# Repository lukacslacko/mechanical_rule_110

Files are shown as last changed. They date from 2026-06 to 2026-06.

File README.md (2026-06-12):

# MECH-110 — a 3D-printable mechanical Rule 110 machine

A hand-cranked, fully 3D-printable machine that computes the
[Rule 110](https://en.wikipedia.org/wiki/Rule_110) cellular automaton —
which is Turing complete — on punched paper tape. One crank revolution
reads three neighboring cells from the input tape, decides the next-generation
cell mechanically, and punches it (plus a fresh sprocket hole) into the
output tape. No springs, no electronics, no metal parts.

The entire mechanism was designed *and verified* in software before printing:
every part is generated parametrically, the full cycle is collision-swept in
all 8 input states, and the assembly order is checked step by step — so
nothing has to be assembled "through the fourth dimension".

## The trick: no 8-way decoder needed

Rule 110 factors into

```
new = (C OR R) AND NOT (L AND C AND R)
```

so instead of an 8-position code wheel, the logic train is just:

- three sensing **pins** that drop into tape holes,
- an **AND3 guillotine** plate resting on all three pin collars (descends
  fully only for 1-1-1) carrying a blocker finger,
- two **OR rockers** (one per pin C, R) whose tips drive
- a horizontal **swing-arm interposer** that slides a block between the
  cam-driven hammer and the data punch.

The 111-veto wins its race by construction: pins ride a cam-timed bail down,
so all drops are rate-synchronized; the blocker enters the swing path before
the arm can start moving.

## Highlights

- **Geneva drive**: 6-slot Geneva + locking ring indexes both tapes exactly
  one 8 mm pitch per revolution; the locking crescent is computed numerically
  from the swept wheel silhouette.
- **Rib cams + slide-in keys**: positive-return cams that still allow the
  one-piece camshaft to drop radially into open bearings — the window
  followers are closed by snap-in keys after the shaft is seated.
- **Single source of truth**: cam lift functions, the kinematic model and the
  cam solids all derive from the same code (`camprofiles.py`), so geometry
  and simulation cannot disagree.

## Verification pipeline

| stage | command | what it proves |
|---|---|---|
| logic & kinematics | `pytest tests/` | the mechanism model computes Rule 110 in all 8 cases; phase discipline; veto race; cycle closure |
| motion sweep | `python scripts/verify_motion.py` | 8 cases × 360° × 1°: no part-pair interference (FCL + exact mesh booleans) |
| assembly order | `python scripts/verify_assembly.py` | a 51-step insertion sequence with swept approach paths |
| viewer | `python scripts/export_viewer.py` | animated three.js model → `out/viewer.html` |

## Assembly

**[Step-by-step assembly guide with renders → ASSEMBLY.md](ASSEMBLY.md)** —
generated from the same collision-verified insertion sequence that
`scripts/verify_assembly.py` checks.

## Quick start

```sh
uv venv .venv && uv pip install --python .venv/bin/python \
    build123d trimesh python-fcl manifold3d shapely scipy rtree networkx pytest
.venv/bin/python -m pytest tests/ -q
.venv/bin/python scripts/build_stls.py        # writes out/parts/*.stl
.venv/bin/python scripts/verify_motion.py
.venv/bin/python scripts/export_viewer.py     # open out/viewer.html
```

Open `out/viewer.html` in a browser: drag the crank-angle slider, pick the
(L,C,R) input case, press play.

## Layout of the repo

- `DESIGN.md` — full mechanism architecture and the design decisions.
- `STATUS.md` — current verification status and open items.
- `src/mech110/` — parameters, cam profiles, kinematics, world layout, the
  parametric part builders (build123d), Geneva geometry, assembly registry.
- `scripts/` — STL export, motion sweep, assembly check, viewer export.
- `out/parts/` — generated STLs; `out/viewer.html` — the animated model.

## Status

Motion-certified (zero interference across all sampled states); assembly
sequence verified with a handful of residual snap-fit contacts still being
classified — see `STATUS.md`. Not yet printed: tolerance/printability review
is the next step. This is a "Turing complete in principle" demonstration
piece, not a practical computer — exactly as intended.

## License

MIT

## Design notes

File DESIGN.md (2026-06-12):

# MECH-110 — a 3D-printable Rule 110 machine on punched paper tape

One crank revolution = one machine cycle = one cell of the next generation
computed and punched. Hole = 1, no hole = 0.

## 0. The logic simplification (no 8-way code wheel needed)

Rule 110: new(i) = f(L, C, R) with table
111→0, 110→1, 101→1, 100→0, 011→1, 010→1, 001→1, 000→0.

f is 0 exactly for {111, 100, 000}. Since 100 and 000 are exactly the patterns
with C=0 and R=0:

    new = (C OR R) AND NOT (L AND C AND R)

Mechanically:
- **AND3** = a guided "guillotine" plate whose three feet rest on the collars
  of all three sensing pins. It descends fully only if *all three* pins drop
  into holes (min function), and carries a blocker finger.
- **OR** = two independent gravity-follower rockers (one for pin C, one for
  pin R), see-saws on a common axle: the ledge side rests on its pin's collar
  (one-way), so the tip side rises when *either* pin drops (max function at
  the contact). One-way resting contacts mean a stalled rocker can never
  prevent a pin from completing its drop — the logic is fully decoupled.
- The rocker tips ride in a 45° V-groove on the foot of a **swing-arm
  interposer** rotating about a *vertical* pivot: rising tips swing the
  interposer block horizontally (at constant height!) into the gap between
  the punch hammer and the data punch head; descending tips pull it back out
  (positive both ways, no springs, no gravity bias needed).
- The AND3 finger, when fully down, stands in the swing path and stops the
  arm after ~1 mm of block travel (= veto). Veto wins the race by
  construction: pins don't free-fall, they ride the cam-controlled bail down,
  so all drops are rate-synchronized; the finger enters the swing path at
  0.8 mm of descent while the V-groove lag delays arm motion until ~1.1 mm.

So: 3 pins + 1 plate + 2 rockers + 1 swing arm replace the 8-position wheel.

## 1. Tape format

- Paper strip, width 25 mm (cut from 57 mm adding-machine roll, or any paper).
- Row pitch P = 8 mm along the tape.
- Track 1 (guide/sprocket): ⌀3.2 mm holes, every row, near reference edge.
- Track 2 (data): ⌀4.0 mm holes, hole = 1.
- Two parallel tape paths through the machine, side by side:
  path A = input (reader), path B = output (punches).
  Loop mode: the tape leaving B U-turns outside the machine and re-enters A.

## 2. Coordinate system & layout

X = tape travel direction, Y = across tape (all shaft axes along Y), Z = up.

- Tape bed (with die holes, sprocket grooves, chad chute) at mid height.
- **Sprocket shaft** above the tape, teeth pointing down through the guide
  holes into bed grooves: two 6-tooth sprockets (pitch radius = 6P/2π ≈ 7.64 mm),
  one per tape path, on one shaft → both tapes advance in lockstep.
- **Main camshaft** higher up, parallel. Carries all cams + Geneva driver +
  crank. Vertical center distance to sprocket shaft = Geneva center distance d.
- **Geneva (6-slot)**: driver crank (radius 0.5·d) on the camshaft's left end,
  wheel (radius 0.866·d) keyed to the sprocket shaft's left end, both outside
  the left frame plate. 60° of wheel per rev = exactly one tooth = one pitch P.
  Locking ring on the driver keeps tapes registered during dwell.
- **Crank handle** on the camshaft's right end.

## 3. Stations

**Reader (over path A)**: three pins at X-spacing P over the data track,
rounded ⌀3.5 tips, sliding in a comb block. A lift bail under the pin collars
(one-way: lift only, lost motion downward) is driven by a groove cam — pins are
held 3 mm above the paper during tape advance, released to settle by gravity
during the read dwell. A pin over a hole drops ~2.5 mm into a bed groove;
a pin over paper rests on it (a few grams — cannot pierce).

**Logic (beside/above reader)**: AND3 bar, OR rocker, pendulum interposer,
as in §0. All gravity-returned; no metal springs anywhere in the machine.

**Punch station (over path B)**: punches guided in a block with integral
stripper; die holes in the bed; chads fall through to the base.
- Guide punch (⌀3.2-hole) — slider with integral punch tip, positively
  driven *both ways* by its cam (window follower). Punches every cycle.
- Data punch (⌀4-hole) — cam-driven hammer; the hammer's face pad presses
  the interposer block which presses the punch-head flange (drive), and a
  C-lip under the flange yanks the punch back out of the paper on retract
  (positive extraction — pierced paper grips the pin too hard for gravity).
  When the interposer is out, the face pad's edge passes clear of both the
  blocked block and the flange: the hammer strokes empty. A small
  counterweighted return rocker holds the idle punch at rest height.
Punch tips are pyramidal piercing points (printable); the design leaves a
drop-in option for steel pins (ground 4 mm nail) if PLA edges dull.

**Cam-follower construction**: every cam is an annular RIB (radial band of
varying center radius, walls = pitch curve ±1.5 mm) protruding axially from
its hub disc; each follower is a slider with a window straddling the rib —
lower boss outside the rib, upper boss inside the ring. The upper boss is a
separate slide-in KEY (inserted along Y after the camshaft is seated), which
is what makes radial drop-in assembly of the camshaft possible at all.
Punch station X is an exact integer multiple of P upstream of sprocket B's
top-dead-center, so machine-punched guide holes land on the teeth.
To start a raw tape, ~3 guide holes are hand-punched with a printed jig.

## 4. Cycle (one camshaft revolution, θ = 0…360°)

| θ | action |
|---|---|
| 0–120° | Geneva engaged → both tapes advance exactly P. Pins held up, punches up. |
| 130–170° | bail lowers; pins settle into holes / onto paper |
| 170–205° | logic settles: AND3 bar lands, OR rocker pushes, interposer swings in (or is vetoed / not pushed) |
| 210–280° | punch stroke down + return (guide always, data iff interposer in) |
| 290–355° | bail lifts pins; bars/rocker/interposer reset by gravity |

Tapes only move while pins and punches are clear; punching only happens during
Geneva dwell (locking ring engaged).

## 5. Frame & assembly strategy

Two side plates + bed + top bearing bridges, joined by printed tab-and-wedge
joints (no screws required; M3 holes provided as backup). All shaft bearings
are **split pillow blocks**: shafts (printed in one piece with their cams /
sprockets) drop in radially, then a printed cap closes the bearing — nothing
has to be threaded axially through closed holes. Geneva wheel and crank key
onto hex shaft ends after the shafts are seated.

## 6. Verification plan (all in software, before printing)

1. **Logic model** (`rule110.py`): discrete simulation of pins → bars →
   interposer → punch for all 8 neighborhoods, asserted equal to Rule 110;
   plus multi-generation tape simulation against a reference implementation.
2. **Single source of truth for motion** (`camprofiles.py`): each cam's lift
   function is defined once, analytically; the cam *solid* is lofted from it
   and the follower *pose* is computed from it ⇒ cam/follower agreement by
   construction. All intended contacts are modeled with explicit running
   clearance (≥0.15 mm), so the nominal mechanism has **zero** intersections.
3. **Motion collision sweep** (`verify/collide.py`): θ sampled at ≤1° over a
   full cycle × all 8 input cases (and tape-with-holes solids in the loop);
   pairwise mesh collision via FCL. *Any* intersection = design error.
   Near-miss report (<0.15 mm clearance) as warnings.
4. **Assembly check** (`verify/assemble.py`): every part has an ordered
   insertion path (sequence of linear moves); each step is sweep-checked
   against the union of already-placed parts. Catches "needs 4th dimension".
5. **Printability** (`verify/printability.py`): per part — bed fit
   (220×220×250 default), min wall ≥ 1.2 mm, chosen print orientation noted,
   overhang sanity.
6. **Animated viewer** (`export/viewer.py`): self-contained three.js HTML,
   θ slider + play, selectable input case, exploded-view assembly animation.

## 7. Print parameters (defaults, all in `params.py`)

PLA, 0.4 nozzle. Running fits 0.25 mm/side, locational 0.15, press 0.05.
Shafts ⌀8 printed. Bed 220×220×250.

## 8. Registration & bookkeeping

Output row is punched k·P offset from the input row being read (k = fixed
station offset). In two-tape mode this is just indexing; in loop mode it adds
a constant spatial shift per generation, which composes harmlessly with the CA.

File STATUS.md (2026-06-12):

# MECH-110 status (end of session 1)

## VERIFIED
- Logic+kinematics: 19 tests green (mechanism == Rule 110 for all 8 cases,
  phase discipline, 111-veto race, cycle closure).
- MOTION: full sweep CLEAN - 8 cases x 360deg x 1deg, all 44 parts, fcl +
  manifold-boolean second pass: zero real interference
  (scripts/verify_motion.py).
- ASSEMBLY (scripts/verify_assembly.py): 51-step sequence runs; structural
  blockers all resolved (axle threads along X after rockers; camshaft turned
  to theta=180 for sprocket-shaft drop; cap pins from outer faces before
  wheel/crank; swing-arm enters tilted -34deg, 8mm rise). 8 residual
  candidate contacts, believed noise/snap-fits but NOT yet boolean-classified:
  key_gp 0.57 (snap barb squeeze ~0.3 by design), key_ham 1.29 (recheck after
  the hub-boss removal!), sprocket_shaft 2.11 & geneva_wheel 1.74 vs camshaft
  (slide-on profile - diagnose with boolean bbox), spk_clip 1.51 (deep snap),
  cp_cl 0.2 (ok), crank 0.045 (ok).
- out/viewer.html: animated three.js model (crank slider, 8 input cases).
- out/parts/*.stl: all printable parts, single solids, watertight after
  vertex merge.

## Statics (added after session 1)
- Force-closure was NOT covered by the geometric sweeps: all three rockers
  were tip-heavy as built (pads would not follow the pins; punch not
  supported). Fixed with pad-side ballast blocks / a larger counterweight;
  locked in by tests/test_mass_balance.py (CenterOf.MASS moment margins).
- STL filenames now carry their assembly-step prefix (NN_name.stl);
  loaders strip it via assembly.strip_step_prefix().

## NEXT
1. Boolean-classify the 8 assembly residuals (reuse verify_motion's bvol).
2. Re-run verify_assembly after the spoked-hub boss removal.
3. Printability pass (bed fit OK by construction; check min walls: gp key
   hole web 0.4, pillar x21..21.5 in and3, rocker foot ribs).
4. Tolerance review for FDM (0.25 running fits assumed).
5. Hand-punch jig for tape leaders (not yet modeled).
6. DESIGN.md final sync (tower guides, east-tip rockers, shelf rail,
   3-spoke hubs, T-cap reversion to pinned plug caps).

Run: .venv/bin/python scripts/{build_stls,verify_motion,verify_assembly,
export_viewer}.py ; tests: -m pytest tests/ -q

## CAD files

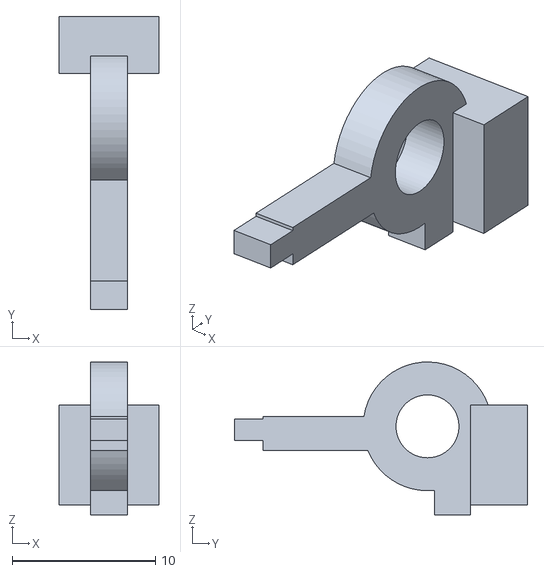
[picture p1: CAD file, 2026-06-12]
out/parts/19_return_rocker.stl
7.00 x 20.5 x 10.7

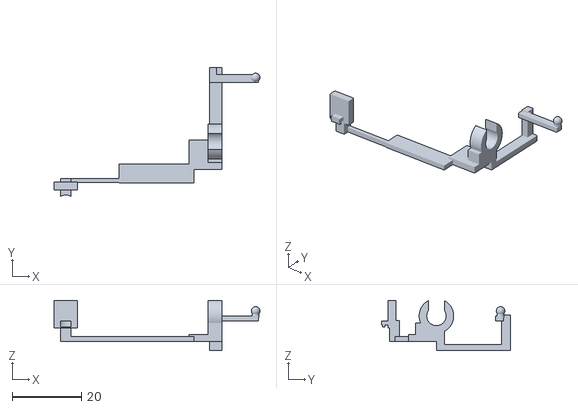
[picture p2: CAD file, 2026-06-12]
out/parts/12_rocker_r.stl
59.4 x 37.3 x 14.5

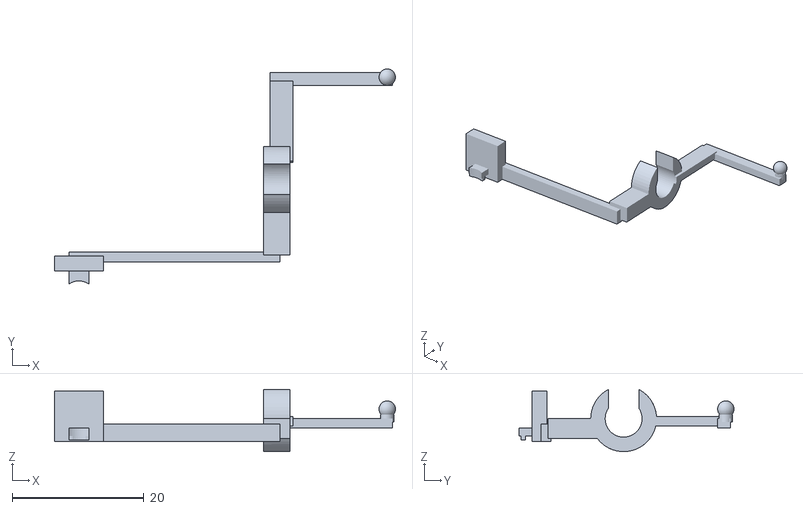
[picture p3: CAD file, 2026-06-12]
out/parts/12_rocker_c.stl
51.7 x 32.6 x 9.44

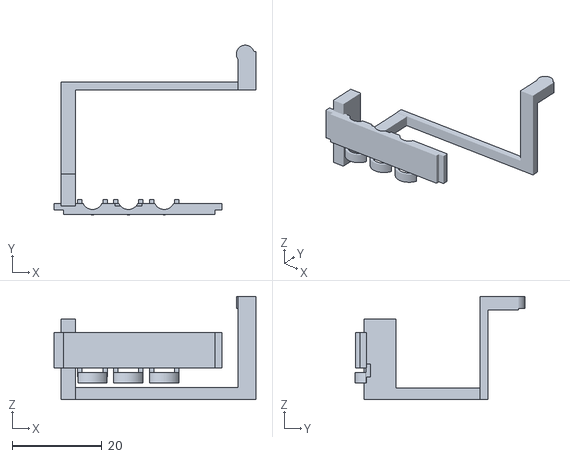
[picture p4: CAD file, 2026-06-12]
out/parts/14_and3.stl
45.1 x 37.9 x 23.0

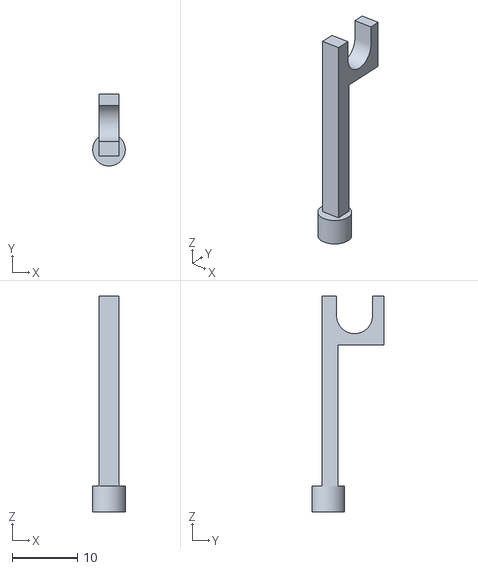
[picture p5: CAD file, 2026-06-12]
out/parts/11_lcol_right.stl
5.00 x 11.0 x 33.0

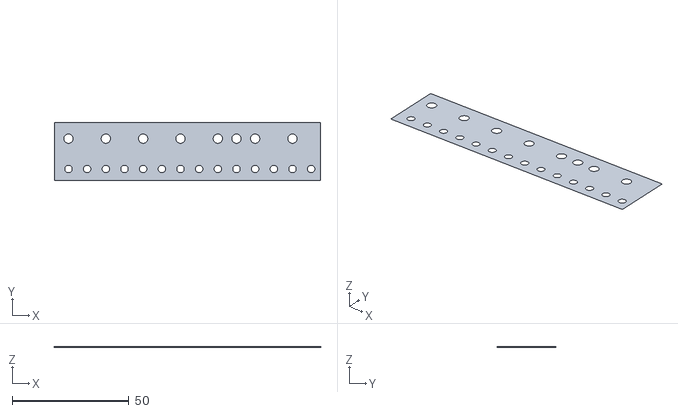
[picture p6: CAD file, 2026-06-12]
out/parts/04_tape_a_110.stl
114.0 x 25.0 x 0.1

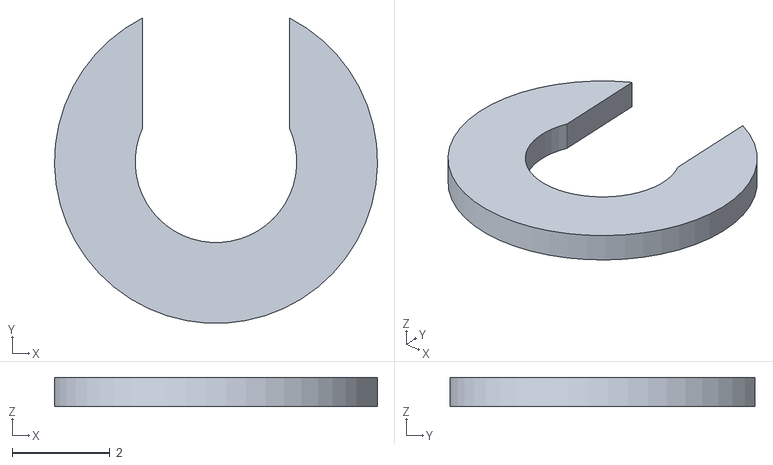
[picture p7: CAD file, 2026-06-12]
out/parts/18_pivot_clip.stl
6.60 x 6.23 x 0.6

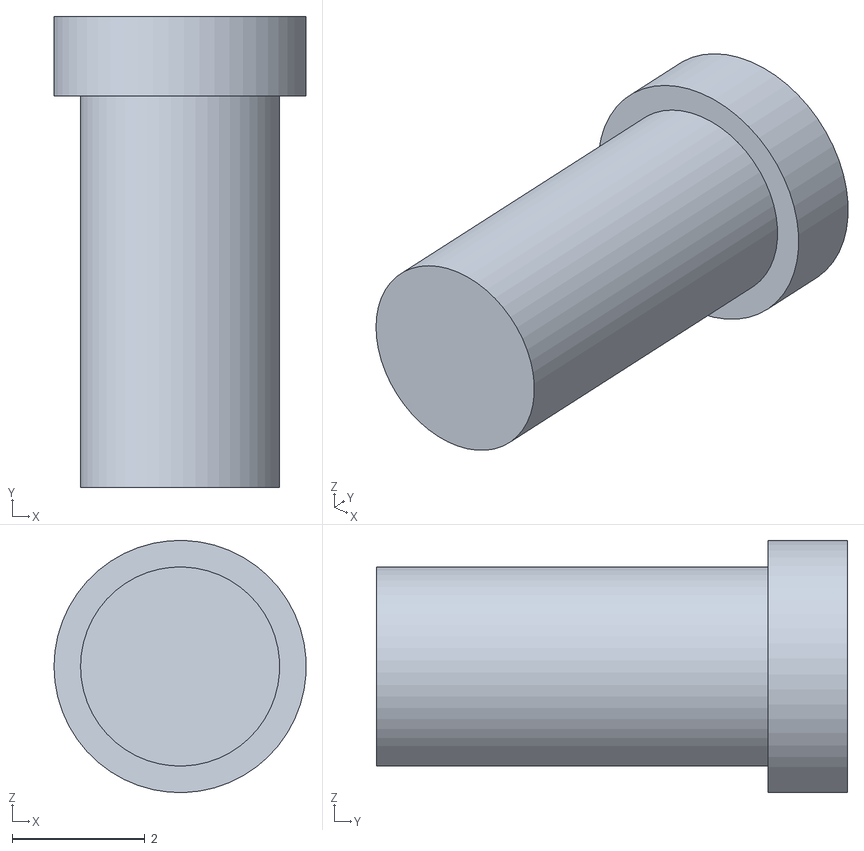
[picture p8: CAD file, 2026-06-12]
out/parts/29_cp_cr2.stl
3.80 x 7.10 x 3.80

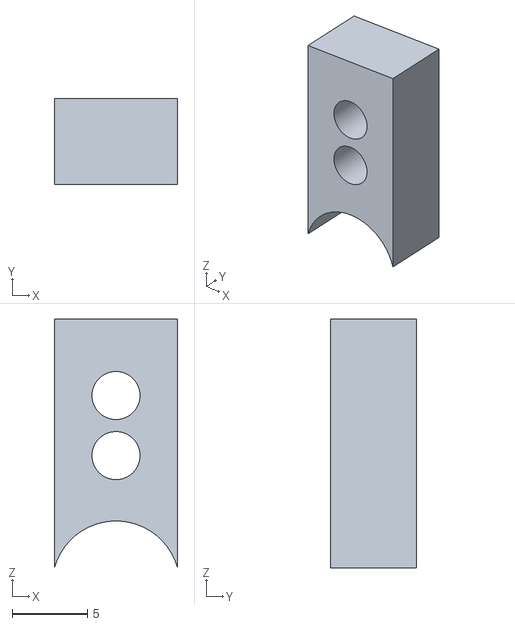
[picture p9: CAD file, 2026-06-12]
out/parts/29_cap_cam_left.stl
8.20 x 5.70 x 16.6

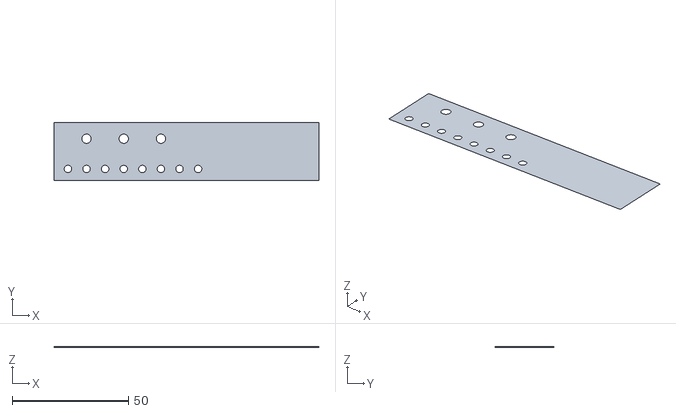
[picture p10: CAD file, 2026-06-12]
out/parts/04_tape_b.stl
114.0 x 25.0 x 0.1

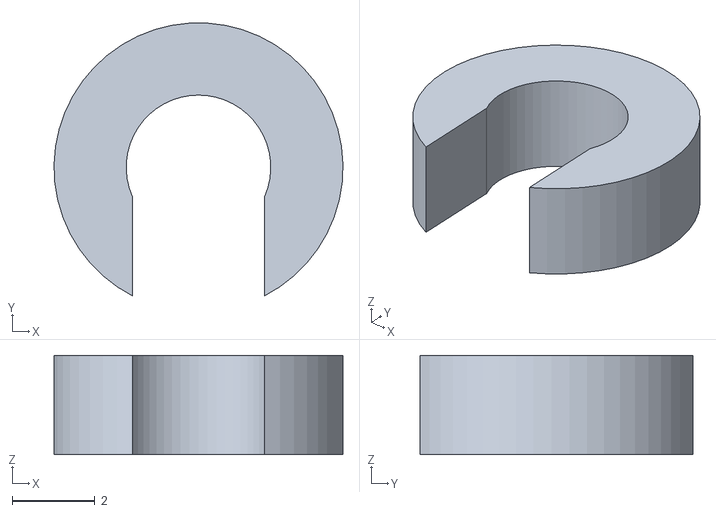
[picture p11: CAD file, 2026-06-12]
out/parts/09_collar_l.stl
7.00 x 6.61 x 2.40

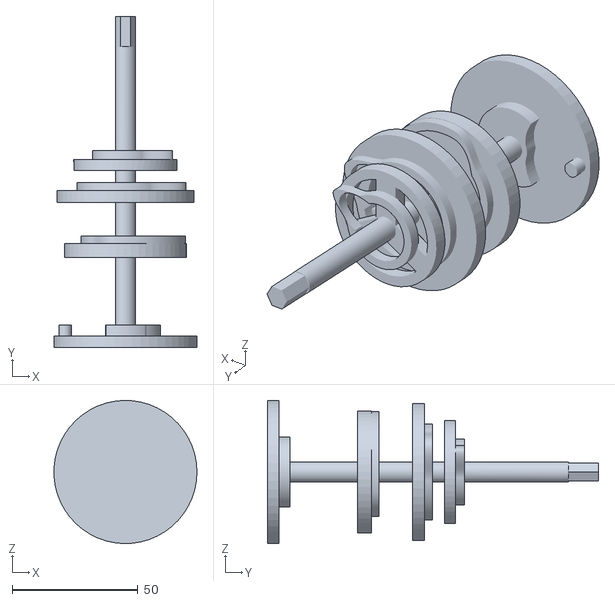
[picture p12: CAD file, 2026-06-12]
out/parts/23_camshaft.stl
56.9 x 132.0 x 57.0

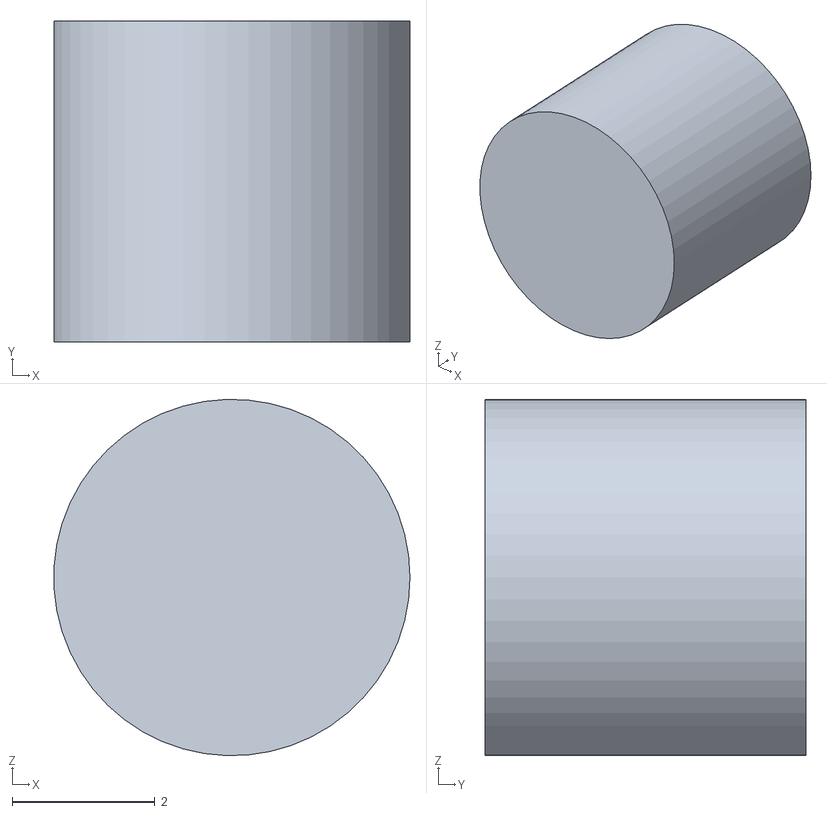
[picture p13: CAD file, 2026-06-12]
out/parts/24_key_bail.stl
5.00 x 4.50 x 5.00

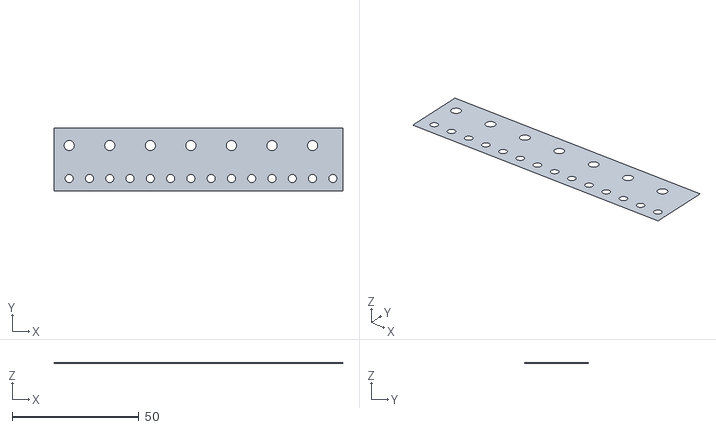
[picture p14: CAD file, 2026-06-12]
out/parts/04_tape_a_010.stl
114.0 x 25.0 x 0.1

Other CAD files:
out/parts/04_tape_a_101.stl
out/parts/04_tape_a_011.stl
out/parts/29_cp_cr1.stl
out/parts/09_collar_r.stl
out/parts/01_base.stl
out/parts/02_plate_left.stl
out/parts/02_plate_right.stl
out/parts/03_bed.stl
out/parts/04_tape_a.stl
out/parts/04_tape_a_000.stl
out/parts/04_tape_a_001.stl
out/parts/04_tape_a_100.stl
out/parts/04_tape_a_111.stl
out/parts/05_cover_a.stl
out/parts/05_cover_b.stl
out/parts/06_comb_bridge.stl
out/parts/07_pin_c.stl
out/parts/07_pin_l.stl
out/parts/07_pin_r.stl
out/parts/08_bail.stl
out/parts/09_collar_c.stl
out/parts/10_punch_block.stl
out/parts/11_lcol_left.stl
out/parts/13_axle.stl
out/parts/15_gallows.stl
out/parts/16_block.stl
out/parts/16_swing_arm.stl
out/parts/20_rr_axle.stl
out/parts/21_data_punch.stl
out/parts/21_hammer.stl
out/parts/22_gp_slider.stl
out/parts/24_key_gp.stl
out/parts/24_key_ham.stl
out/parts/25_sprocket_shaft.stl
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

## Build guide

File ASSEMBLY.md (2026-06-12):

# MECH-110 assembly guide

Step-by-step assembly in the **verified order** — this exact sequence (including insertion directions and the camshaft rotation in step 25) is collision-checked by `scripts/verify_assembly.py`; the images are rendered from the same data by `scripts/render_assembly_guide.py`.

New parts in each step are shown **orange**, slightly offset along their insertion direction (arrow). The near frame plate is drawn translucent so you can see inside.

No screws, springs or metal parts. Snap fits are printed; keep cyanoacrylate handy for the two press-fit pins noted below.

## Bill of parts

| part | qty | note |
|---|---|---|
| base, bed, plate_left/right | 1 ea | print flat |
| comb_bridge, punch_block, gallows, lcol_left/right | 1 ea | bed-peg mounted bridges |
| cover_a, cover_b | 1 ea | tape hold-downs |
| pin / collar | 3 / 3 | identical; collars are snap C-clips |
| bail + key_bail | 1 + 1 | key is a d5 press pin |
| and3, rocker_c, rocker_r, axle | 1 ea | the logic train |
| swing_arm, block, pivot_clip | 1 ea | interposer |
| hammer + key_ham, gp_slider + key_gp | 1+1 ea | cam followers |
| data_punch, return_rocker, rr_axle | 1 ea | data punch set |
| camshaft, crank | 1 ea | print camshaft vertically |
| sprocket_shaft, geneva_wheel, spk_clip | 1 ea | print shaft vertically |
| cap_cam_* , cap_spk_* | 2 + 2 | bearing caps |
| cap_pin3 | 8 | d3 retention pins |

---

## Step 1 — Base plate

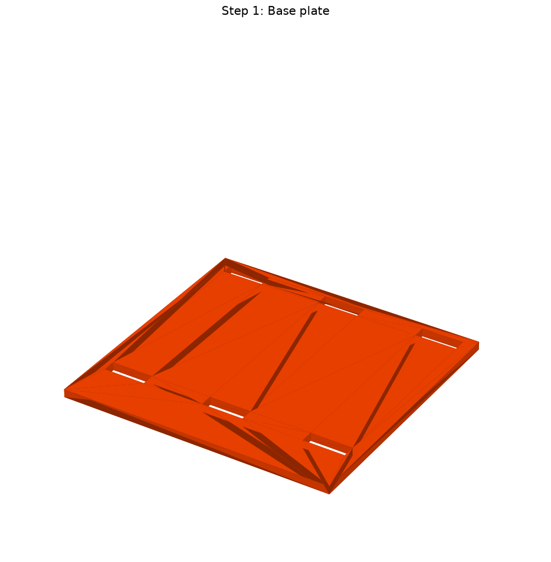
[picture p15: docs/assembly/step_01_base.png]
Step 1: Base plate


Lay the base flat. The rectangular mortises take the frame-plate tabs; everything else stacks on top.

## Step 2 — Frame plates

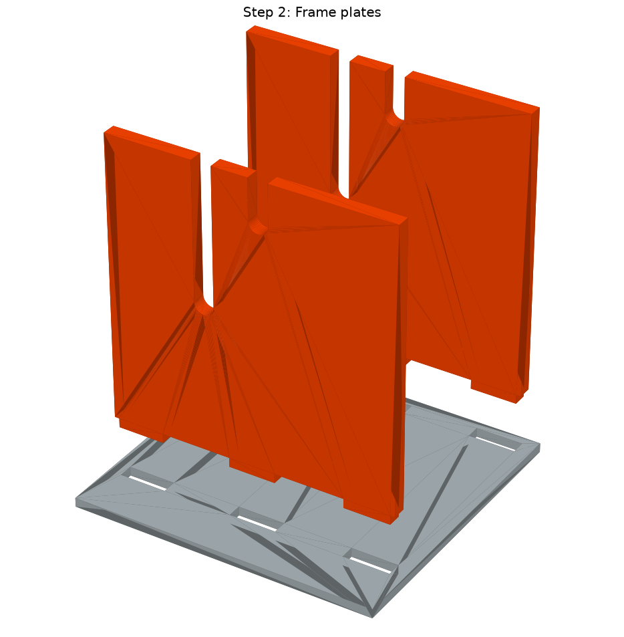
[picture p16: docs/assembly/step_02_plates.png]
Step 2: Frame plates


Drop both plates straight down so their three bottom tabs enter the base mortises. The open-top U-slots are the shaft bearings; the small side holes near the slots take the bearing-cap retention pins later.

## Step 3 — Tape bed

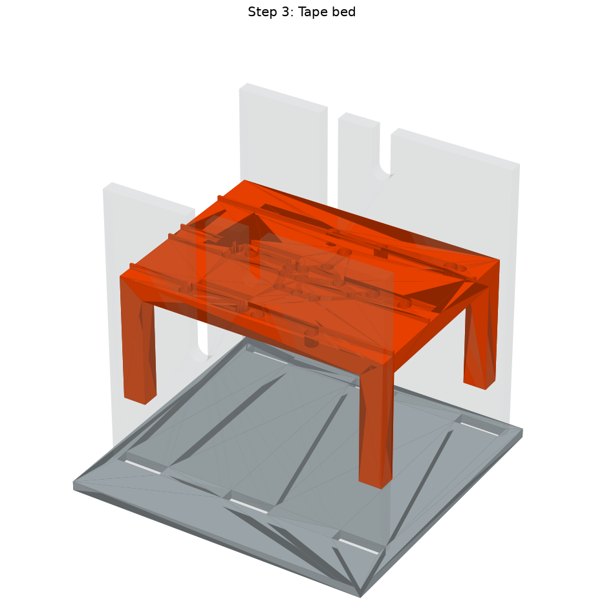
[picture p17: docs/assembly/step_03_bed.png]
Step 3: Tape bed


Lower the bed between the plates until its four legs sit on the base. Top side up: tape rails, sprocket grooves, the three reader-pin holes and the two punch die holes. All later peg-mounted parts plug into the bed's peg holes.

## Step 4 — Paper tapes (reference)

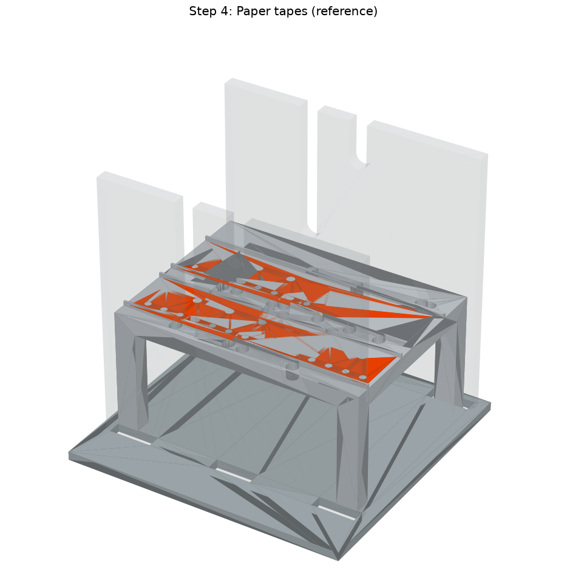
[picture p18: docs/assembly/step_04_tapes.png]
Step 4: Paper tapes (reference)


Shown for reference only: the tapes are threaded LAST, by cranking — the sprocket teeth carry them in (hand-punch ~3 guide holes into each leader first). Input tape A runs in the near lane, output tape B in the far lane; both travel toward -X (to the left here).

## Step 5 — Sprocket hold-down covers

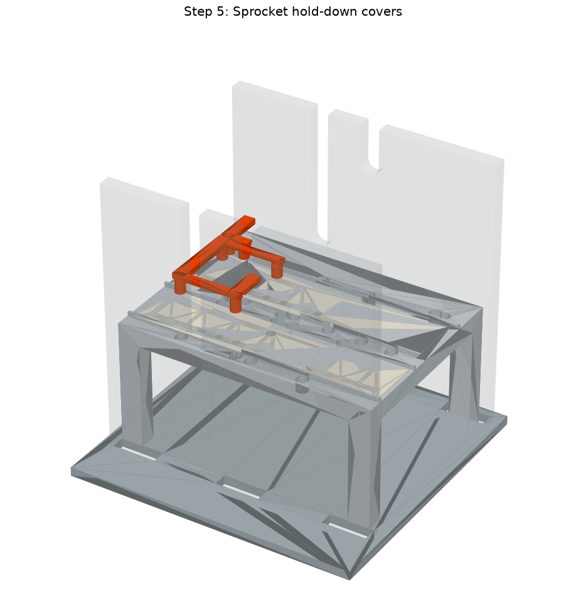
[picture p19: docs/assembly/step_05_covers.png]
Step 5: Sprocket hold-down covers


Press the two covers' pegs into the bed holes flanking the sprocket station. They keep the paper wrapped on the sprocket teeth.

## Step 6 — Reader comb bridge

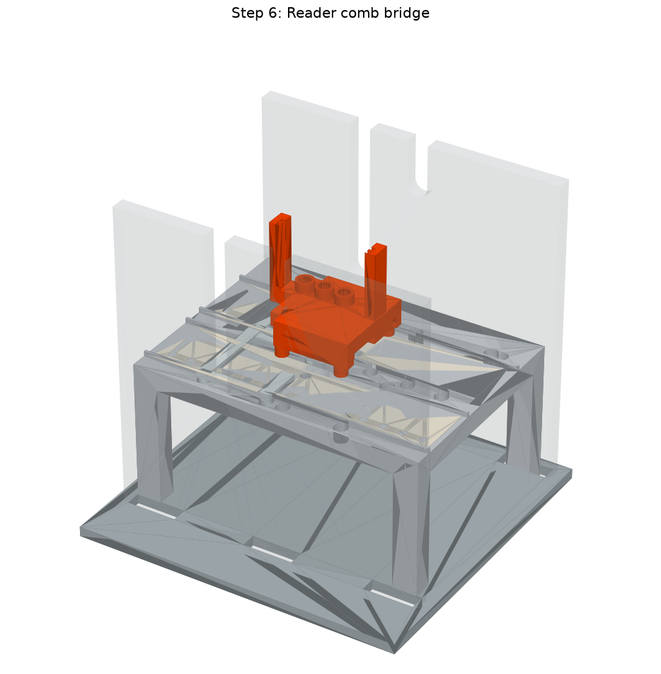
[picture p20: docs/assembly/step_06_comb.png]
Step 6: Reader comb bridge


Press the comb bridge down onto its four bed pegs. It spans tape A as a bridge: its underside is the stripper, the three bores guide the reader pins, and the two end towers carry the vertical grooves that guide the bail and the AND3 plate.

## Step 7 — Reader pins

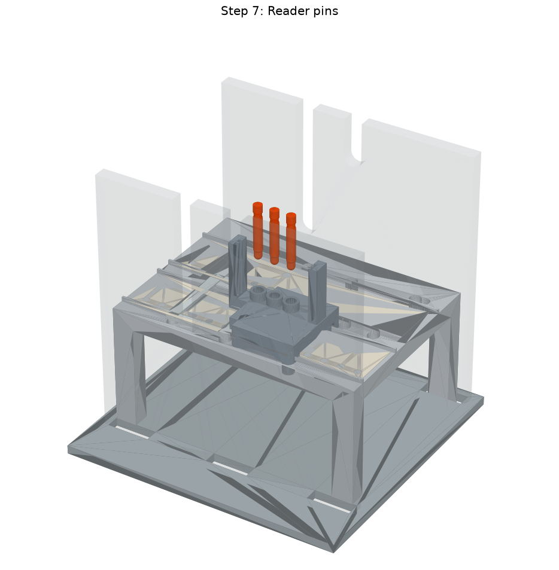
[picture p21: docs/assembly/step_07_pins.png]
Step 7: Reader pins


Drop the three identical pins tip-first into the comb bores. They fall through into the bed holes for now; lift them while clipping on the collars in the next step.

## Step 8 — Lift bail

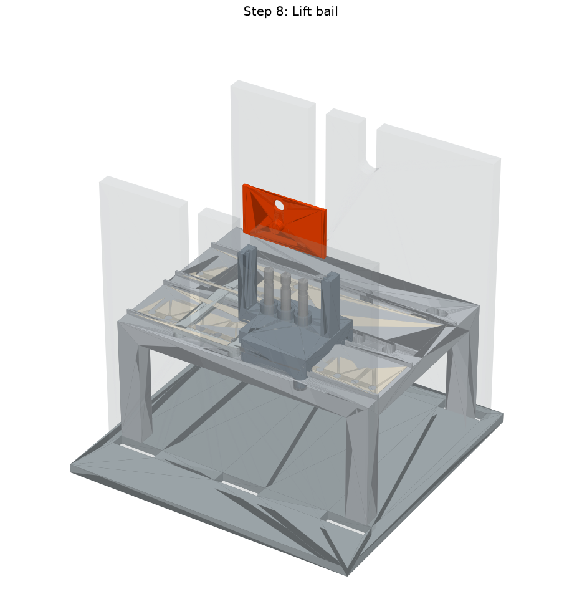
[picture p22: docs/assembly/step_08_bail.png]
Step 8: Lift bail


Slide the bail down: its two end tabs ride the front grooves of the comb towers. The three U-slotted fingers pass around the pin shafts — they will lift the pins by their collars.

## Step 9 — Pin collars

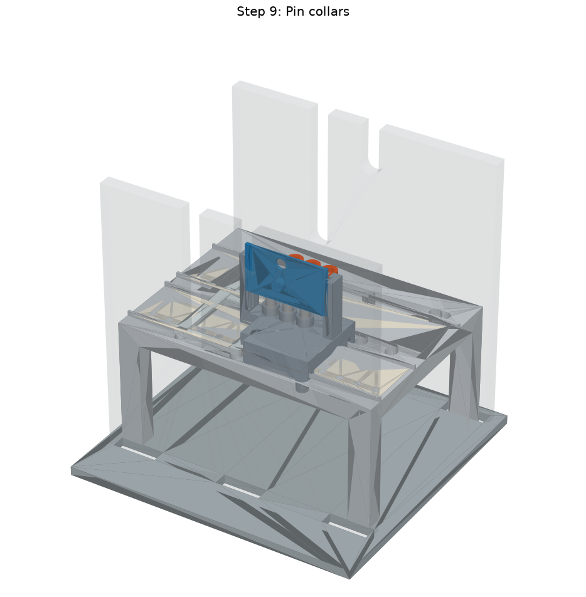
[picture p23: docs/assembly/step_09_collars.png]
Step 9: Pin collars


Hold each pin raised and snap a C-collar sideways (from the front) into its groove. The collar rests on the bail finger below; the AND3 feet and rocker pads will ride on its top face.

## Step 10 — Punch block

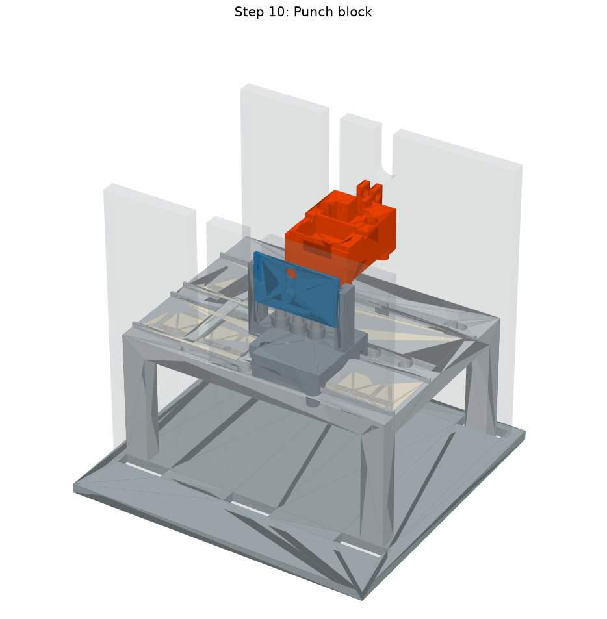
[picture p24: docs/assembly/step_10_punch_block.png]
Step 10: Punch block


Press the punch block onto its four bed pegs. It bridges tape B: stripper underside, guide bores for both punches and the hammer shanks, the return-rocker ears at the back, and the shelf rail that parks the interposer block.

## Step 11 — Rocker axle columns

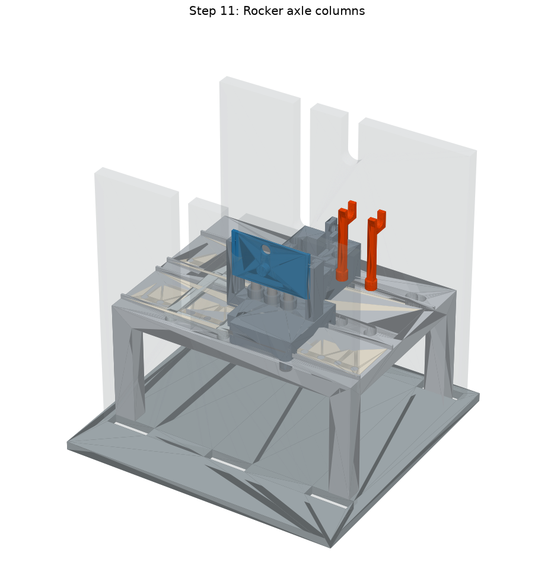
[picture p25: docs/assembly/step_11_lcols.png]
Step 11: Rocker axle columns


Press the two L-columns into their bed holes in the corridor between the tapes. Their open cradles will hold the rocker axle.

## Step 12 — OR rockers

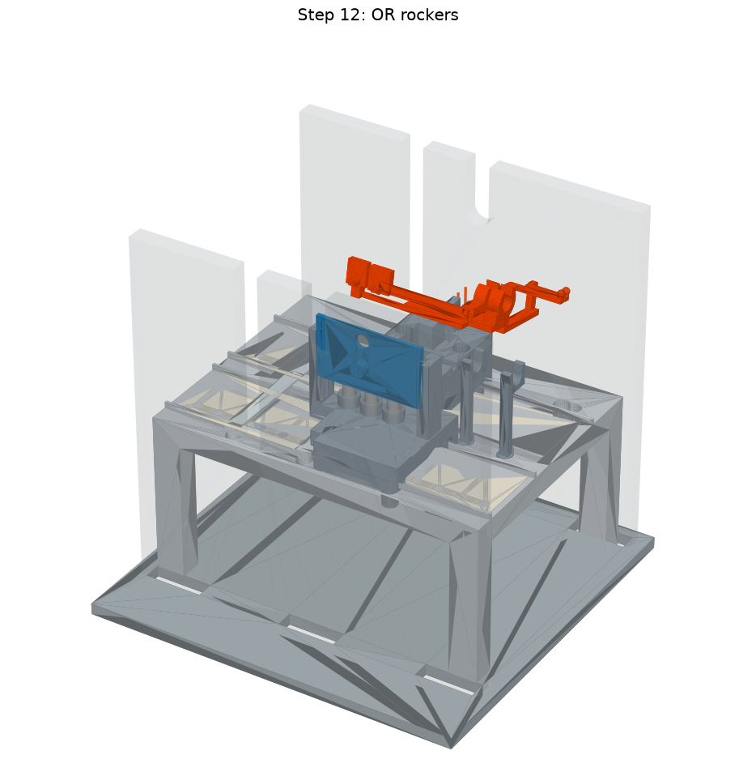
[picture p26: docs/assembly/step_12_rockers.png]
Step 12: OR rockers


Set the two rockers in place: each ledge pad rests on its pin collar (C and R), the long arms route around the cam stack to the east side of the machine. Their hubs line up with the axle cradles.

## Step 13 — Rocker axle

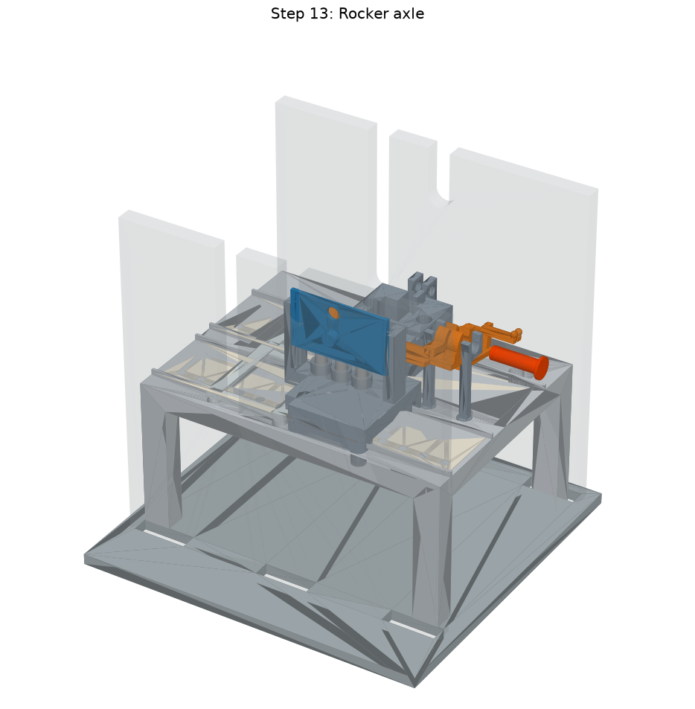
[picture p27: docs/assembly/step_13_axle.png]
Step 13: Rocker axle


Thread the axle rod westward (from the right) through the right cradle, both rocker hubs and the left cradle until the head seats. A drop of glue at the plain end keeps it from walking.

## Step 14 — AND3 guillotine

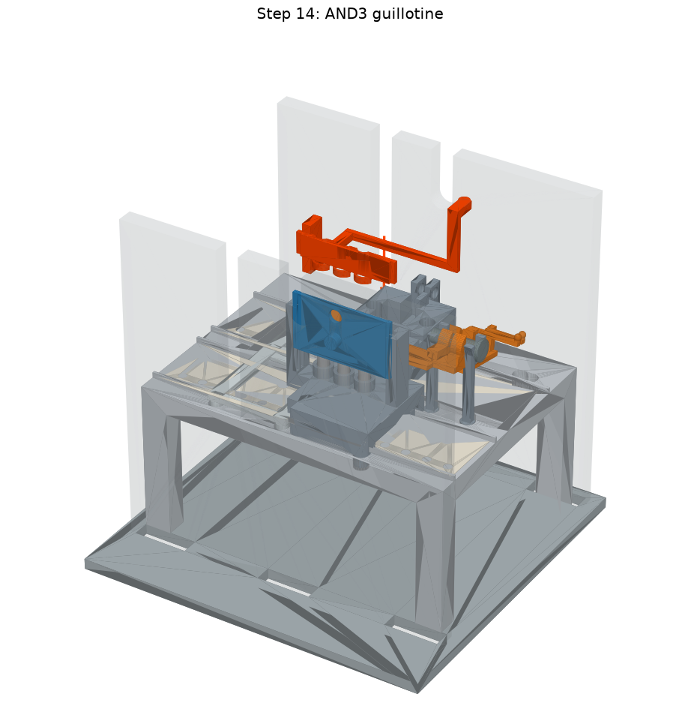
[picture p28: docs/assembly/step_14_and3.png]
Step 14: AND3 guillotine


Lower the AND3 plate: its end tabs ride the rear grooves of the comb towers, the three crescent feet land around the pin collars, and the long blocker arm snakes west and over to the punch station. It must slide freely — it is lifted by whichever pin sits highest.

## Step 15 — Swing-arm gallows

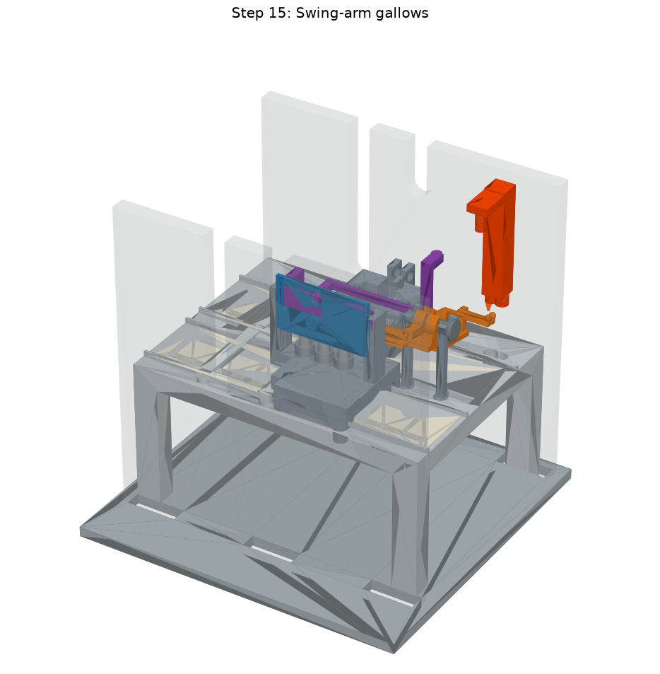
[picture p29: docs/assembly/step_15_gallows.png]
Step 15: Swing-arm gallows


Press the gallows onto its two bed pegs behind tape B. The vertical pin hanging from its arm is the swing-arm pivot.

## Step 16 — Interposer arm (tilted entry)

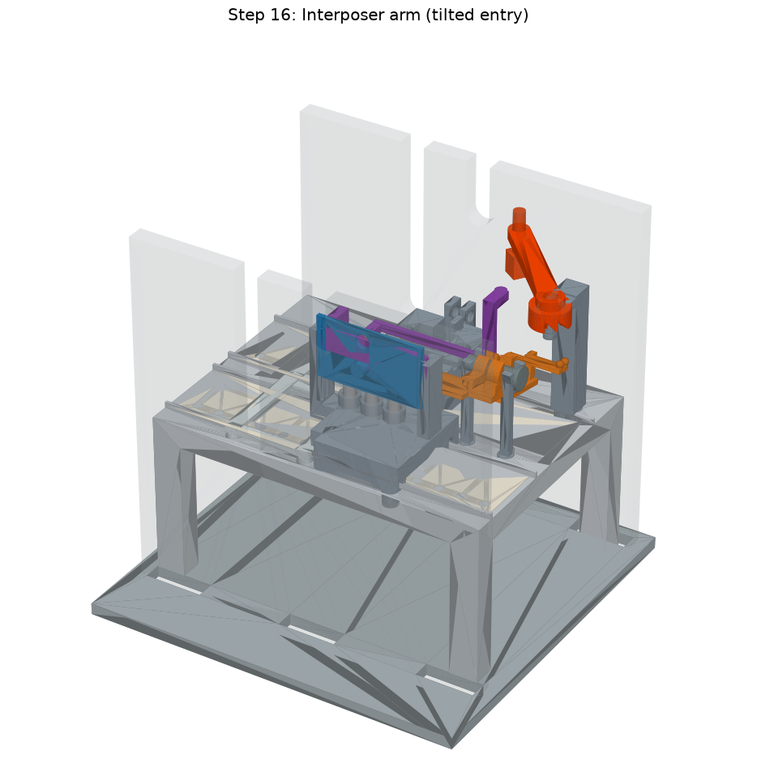
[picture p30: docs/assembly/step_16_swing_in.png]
Step 16: Interposer arm (tilted entry)


Hang the block's stem in the arm's end bore first (off the machine). Then, with the arm rotated about 34 degrees clockwise from its rest attitude, raise the assembly so the hub slides onto the gallows pin. The tilt routes the block up through the free column behind the return-rocker ears — straight-in does not fit.

## Step 17 — Interposer arm (rotate home)

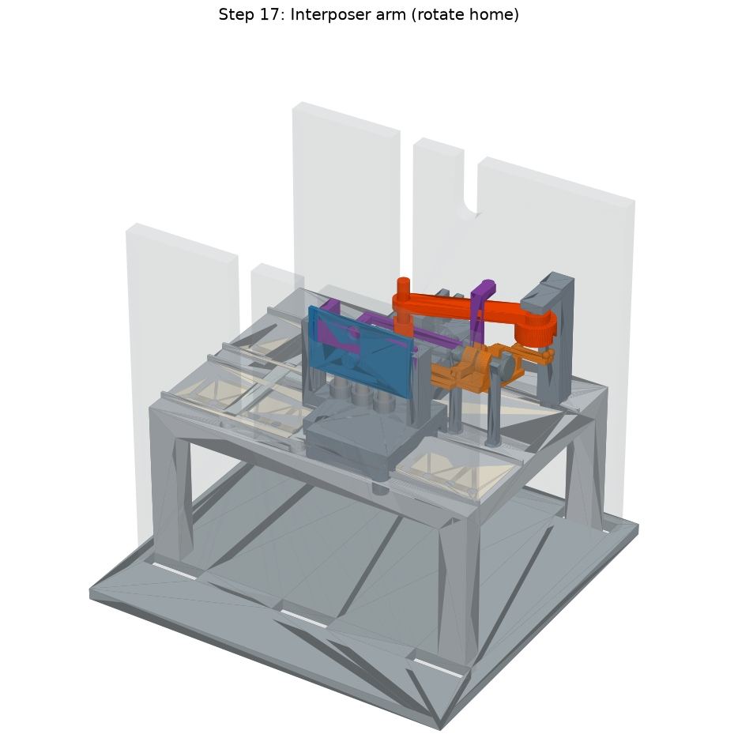
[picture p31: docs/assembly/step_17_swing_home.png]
Step 17: Interposer arm (rotate home)


Rotate the arm counterclockwise to its rest position: the block settles onto the shelf rail, ready to swing over the punch flange.

## Step 18 — Pivot clip

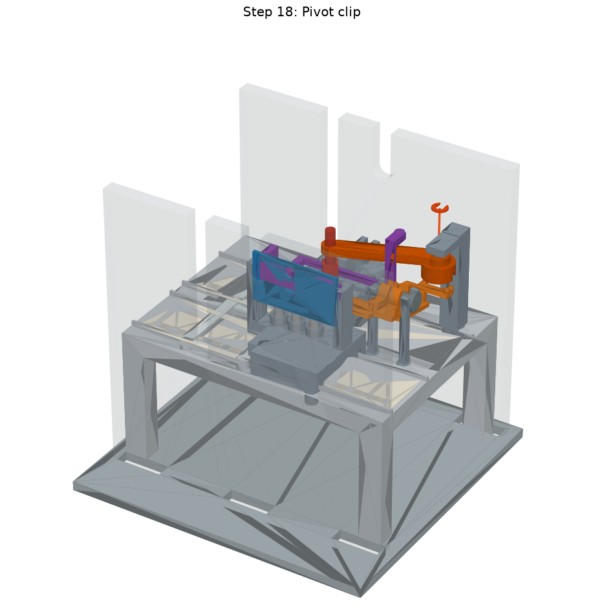
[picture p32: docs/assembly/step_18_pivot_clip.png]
Step 18: Pivot clip


Push the small C-clip up inside the foot-ring bore and snap it into the groove near the pivot pin's tip — it keeps the arm from lifting off.

## Step 19 — Punch return rocker

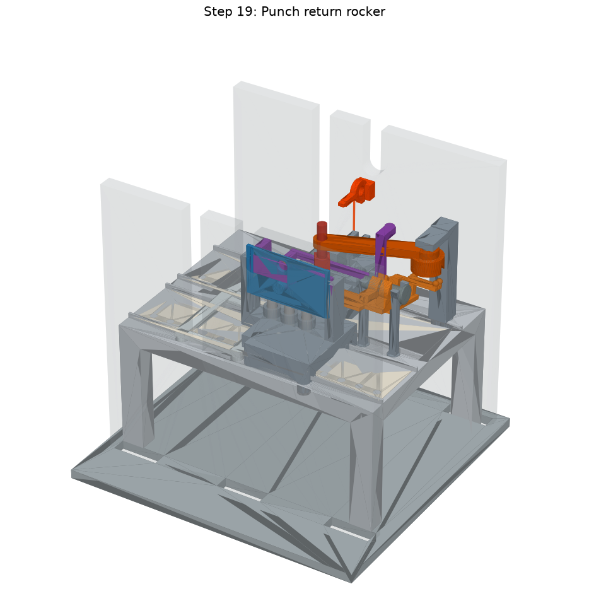
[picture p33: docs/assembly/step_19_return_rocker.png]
Step 19: Punch return rocker


Set the return rocker between the ears on the punch block's rear extension, counterweight toward the back, tip pad forward under where the punch flange will sit.

## Step 20 — Return-rocker axle

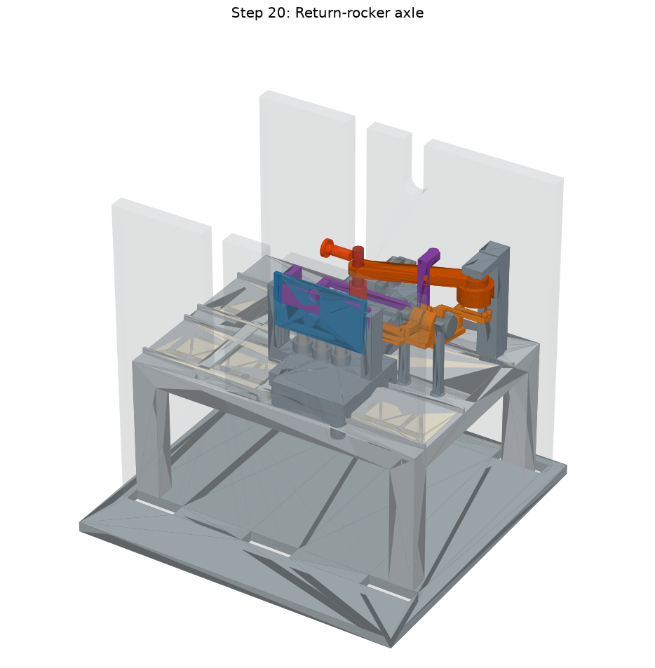
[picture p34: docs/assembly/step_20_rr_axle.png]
Step 20: Return-rocker axle


Push the small axle pin eastward through the ears and the rocker hub until the head seats against the west ear.

## Step 21 — Hammer + data punch

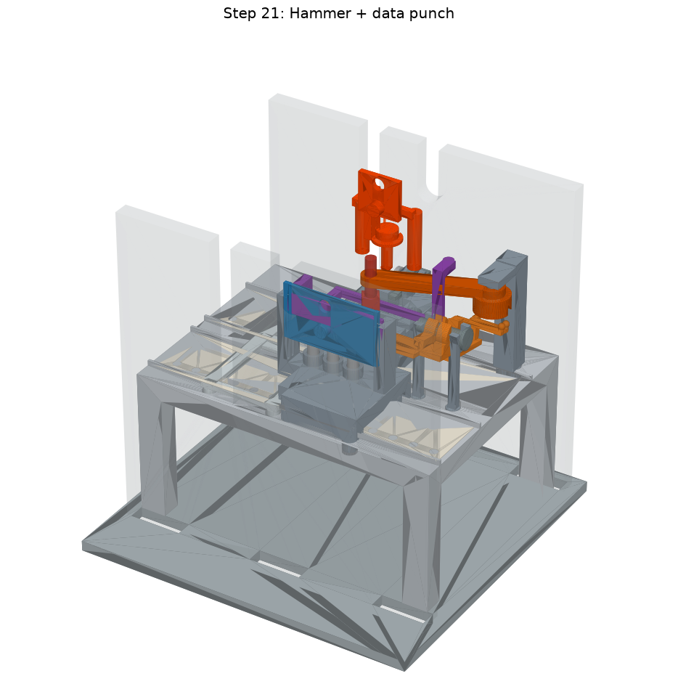
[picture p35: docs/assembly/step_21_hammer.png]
Step 21: Hammer + data punch


Off the machine, slide the data punch sideways into the hammer's C-lip through its front opening (flange above the lip). Lower both together: the hammer's two shanks and the punch enter their bores; the punch flange comes to rest on the return-rocker pad.

## Step 22 — Guide punch slider

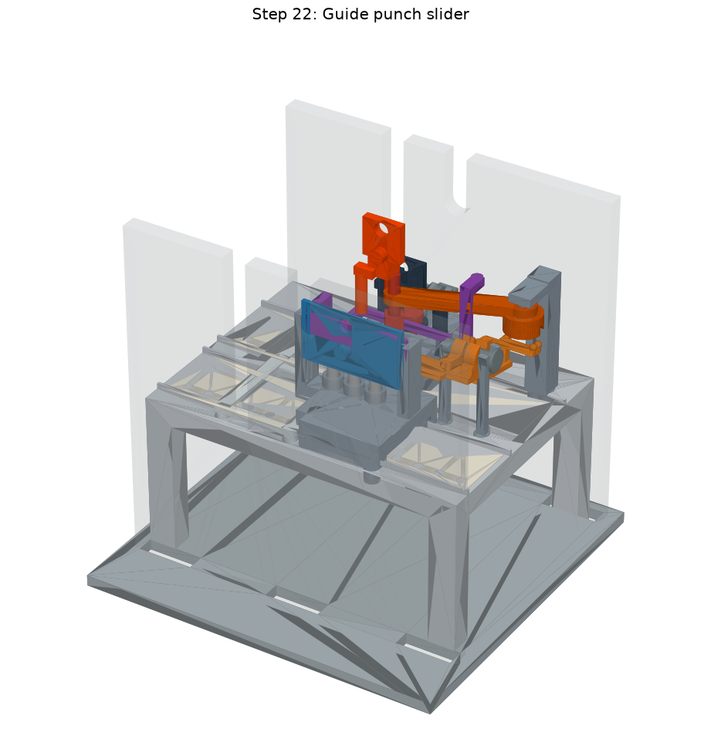
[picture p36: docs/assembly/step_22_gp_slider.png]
Step 22: Guide punch slider


Lower the guide-punch slider: punch shank and the short dummy shank enter their bores; the fork plate hangs where the cam rib will run.

## Step 23 — Camshaft

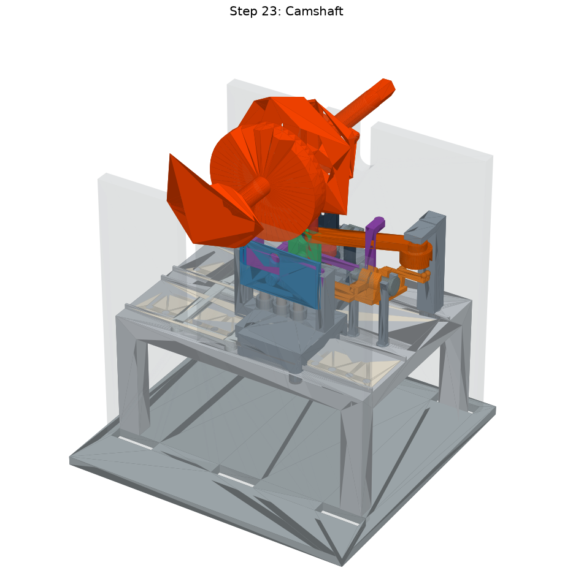
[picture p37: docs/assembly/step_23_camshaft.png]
Step 23: Camshaft


With every follower resting in place, drop the one-piece camshaft straight down into the open plate bearings. The three cam ribs land 0.3 mm above their follower bosses — nothing should touch. Set it to the reference angle (Geneva pin pointing straight down at the sprocket slot).

## Step 24 — Follower keys (camshaft ghosted)

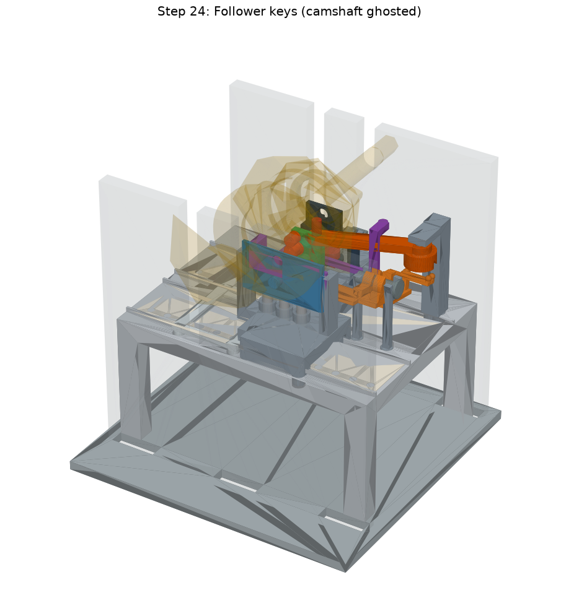
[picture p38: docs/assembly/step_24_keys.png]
Step 24: Follower keys (camshaft ghosted)


Close each follower window with its key so the cams drive both ways: the bail key presses in from the front through the bail plate (glue it); the guide-punch and hammer keys are snap pins inserted from the front corridor — they thread between the spokes of the cam hubs (keep the camshaft at the reference angle) and click into their plate holes.

## Step 25 — Sprocket shaft (camshaft at 180°, ghosted)

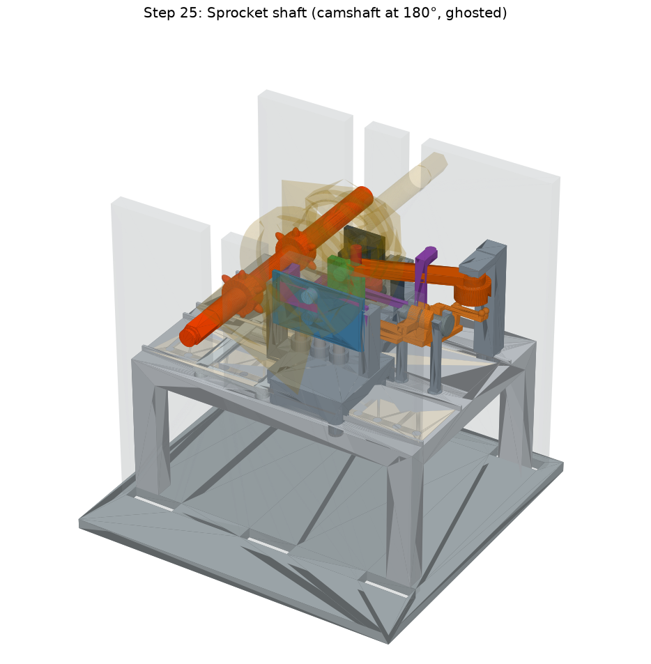
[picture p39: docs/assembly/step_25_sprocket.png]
Step 25: Sprocket shaft (camshaft at 180°, ghosted)


FIRST turn the crank-end of the camshaft half a revolution (the Geneva pin now points up) — otherwise the pin blocks the drop path. Then lower the sprocket shaft into its bearings: both sprockets' teeth dip into the bed grooves.

## Step 26 — Sprocket bearing caps

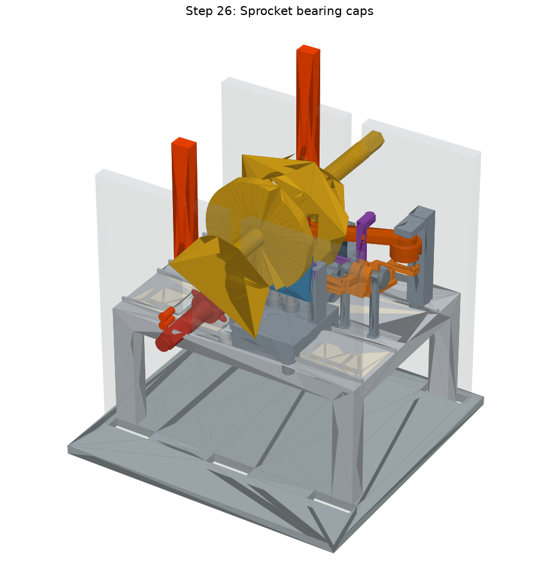
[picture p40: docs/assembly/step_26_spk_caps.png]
Step 26: Sprocket bearing caps


Drop the two tall caps into the plate slots over the sprocket journals and push the four d3 retention pins in from the OUTER plate faces (do this before the Geneva wheel blocks the left side).

## Step 27 — Geneva wheel

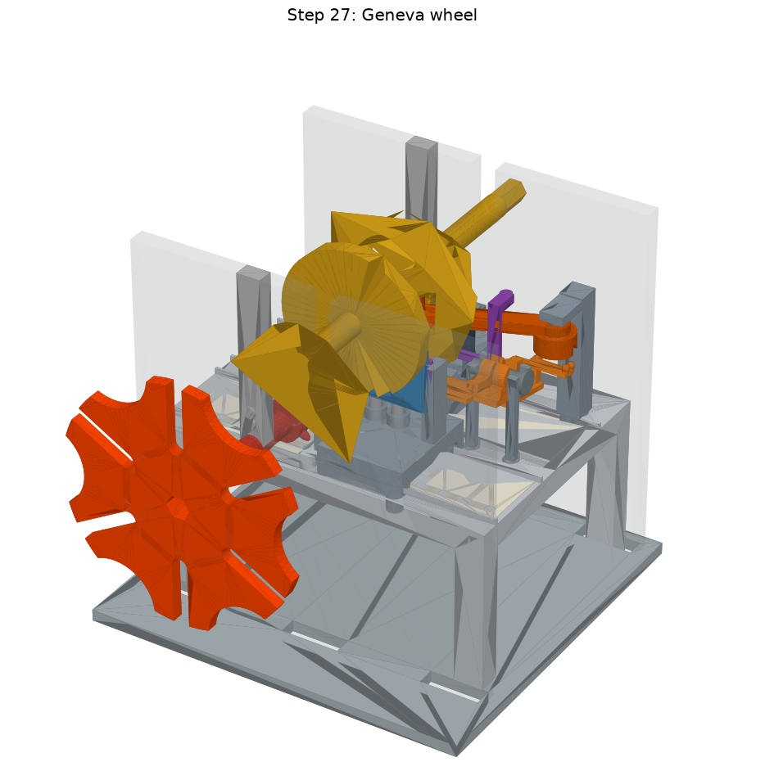
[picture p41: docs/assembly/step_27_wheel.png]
Step 27: Geneva wheel


Slide the wheel onto the left hex stub (any of the 6 orientations works — pick the one where a slot points up at the driver pin and the locking ring nests in a concave arc). Snap the C-clip onto the stub groove.

## Step 28 — Geneva wheel clip

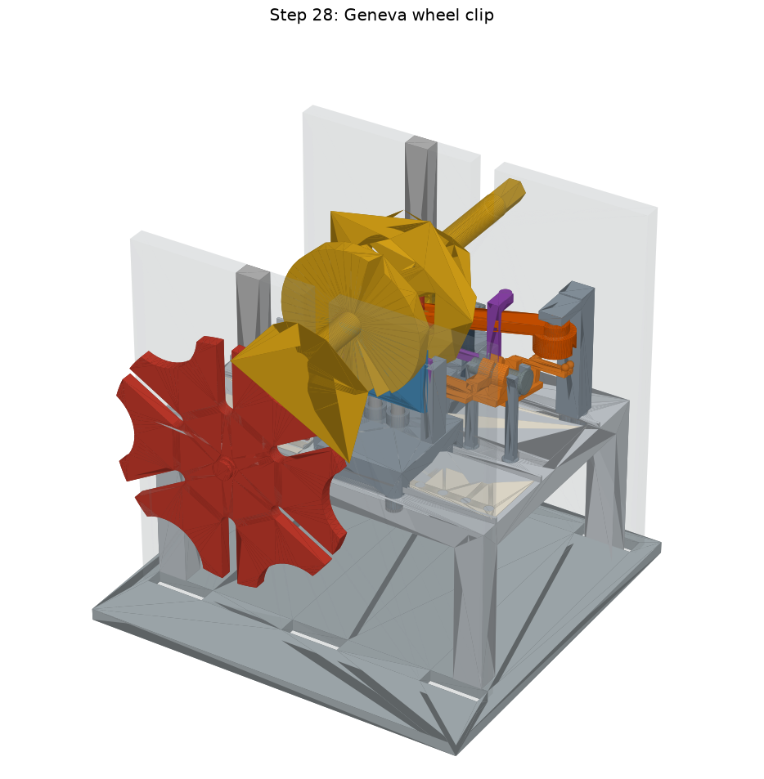
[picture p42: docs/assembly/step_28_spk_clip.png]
Step 28: Geneva wheel clip


Snap the retaining C-clip into the stub groove in front of the wheel hub. Now turn the camshaft back to the reference angle.

## Step 29 — Camshaft bearing caps

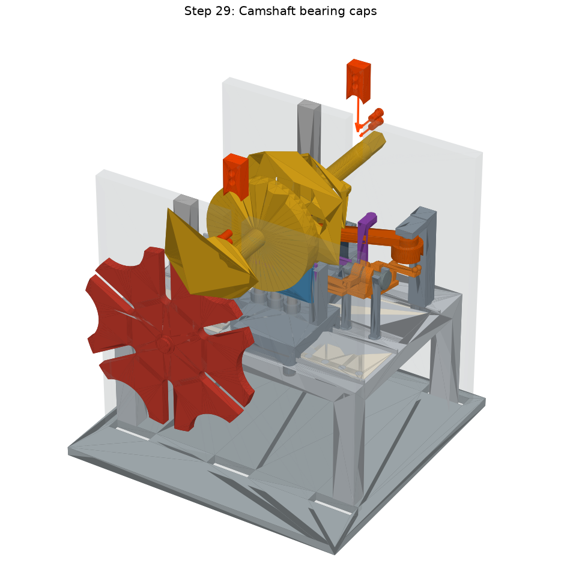
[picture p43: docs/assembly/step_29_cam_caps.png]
Step 29: Camshaft bearing caps


Drop the two short caps into the camshaft slots and push the four retention pins in from the outer faces. These caps take the punch reaction, so seat the pins fully.

## Step 30 — Crank

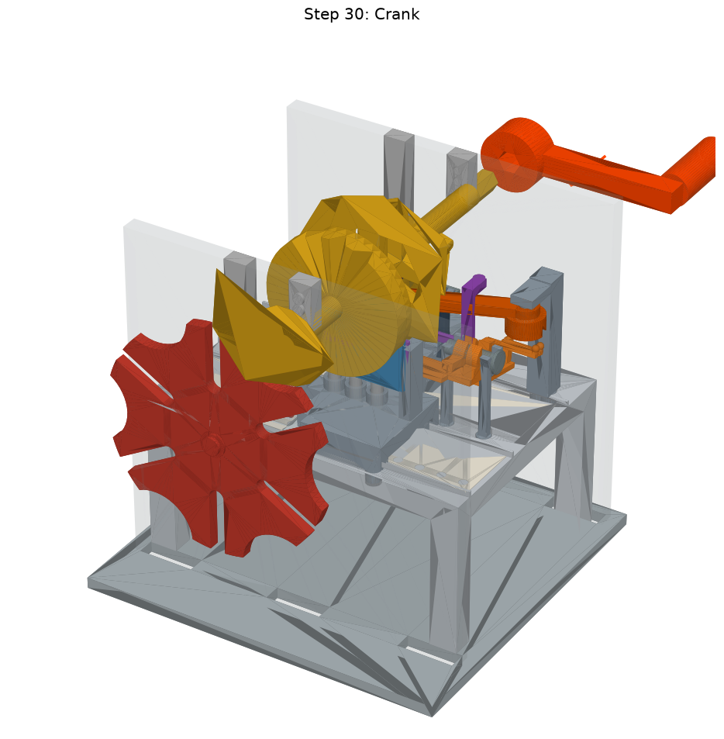
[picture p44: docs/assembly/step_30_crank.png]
Step 30: Crank


Push the crank onto the right hex stub. Done — crank clockwise (looking from the crank side): tape advances, pins read, logic decides, punches fire at the bottom of the cycle.

## Done

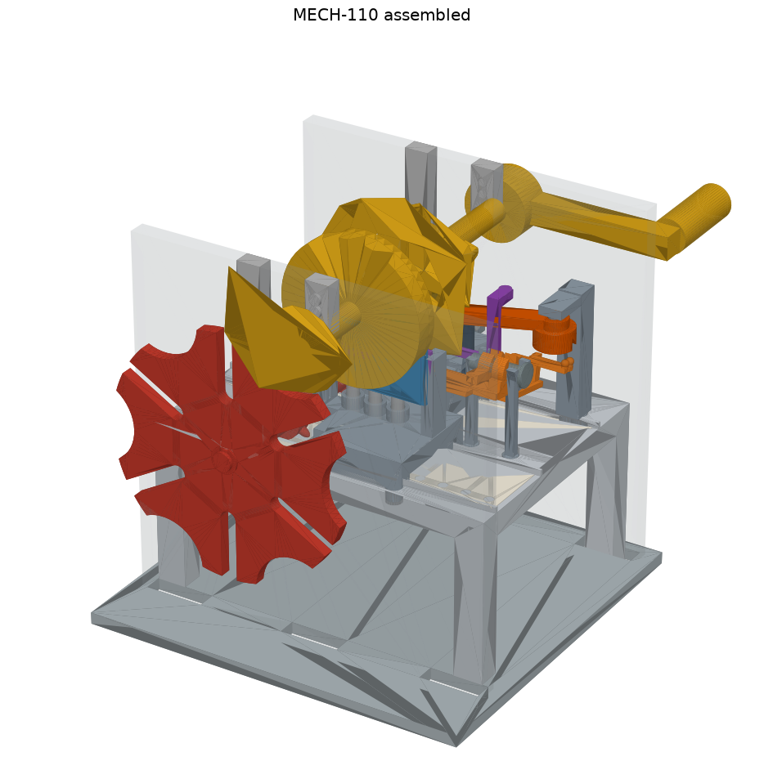
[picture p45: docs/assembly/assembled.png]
Assembled


Thread the tapes (leaders pre-punched with ~3 guide holes) by cranking, and the machine is ready to compute.

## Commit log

2026-06-12 MECH-110: 3D-printable mechanical Rule 110 machine, verified in software
    Parametric CAD (build123d) + kinematic model + full-cycle collision sweep
    (8 input cases x 360deg) + assembly-order verification + animated viewer.
    [and3.stl, axle.stl, bail.stl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]
2026-06-12 Add step-by-step assembly guide (ASSEMBLY.md + 31 rendered images)
    Renders walk the verified insertion sequence from verify_assembly.py:
    new parts highlighted and offset along their insertion direction, frame
    plates ghosted, camshaft ghosted where it would hide the follower keys.
2026-06-12 Statics fix + build-order STL prefixes
    All three rockers were tip-heavy as built (gravity-follow assumed by the
    kinematic model but never checked): added pad-side ballast to the OR
    rockers, enlarged the punch return counterweight, and locked the margins
    in with tests/test_mass_balance.py. Motion sweep re-certified clean.
    STLs are now named NN_part.stl by assembly step (ASSEMBLY.md order);
    all loaders strip the prefix.
    [01_base.stl, 02_plate_left.stl, 02_plate_right.stl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]
